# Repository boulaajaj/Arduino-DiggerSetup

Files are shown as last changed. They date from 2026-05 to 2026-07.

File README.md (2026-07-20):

# 🚜 Excavator Track Controller

**Tank-style dual-track controller for a ride-on excavator, built on the
Arduino UNO R4 WiFi.** Two FOC brushless motors drive rubber tracks. Two people
can drive it — an RC transmitter operator and a seated rider on a joystick — and
a 3-position switch decides who has authority. Live motor telemetry streams to a
Wi-Fi dashboard you open on your phone.

> The controller's job is deliberately small and predictable: **read the inputs,
> shape them, mix them into left/right track commands, cap them by gear, and send
> a servo-PWM throttle to each ESC.** The ESC's internal FOC owns motor smoothness,
> so there is no closed-loop control or lag on the Arduino side.

---

## ✨ What It Can Do

- **Tank / curvature mixing** — one stick (or wheel + trigger) blends into smooth
  left/right track control; counter-rotating **pivot turn** on the spot at a standstill.
- **Two drivers, one machine** — RC transmitter *and* a rider joystick, with a
  3-position override switch (RC-only / RC-priority / 50-50 blend).
- **Gear caps** — Eco / Normal / Boost wheel-speed limits selectable from the remote.
- **Exponential response curves** — separate throttle and steering expo for fine,
  controllable low-speed handling.
- **Instant failsafe** — loss of the RC signal holds both tracks at neutral.
- **Live Wi-Fi telemetry dashboard** — per-track voltage, current, RPM, power,
  ESC/motor temperatures and battery state, served straight off the board
  (monitoring only — there is no control over Wi-Fi, by design).

---

## 🧰 Uses (Hardware)

| Part | Model | Notes |
| --- | --- | --- |
| **Controller** | **Arduino UNO R4 WiFi** | Renesas RA4M1 (48 MHz, 14-bit ADC, 5 V-tolerant) + onboard ESP32-S3 for Wi-Fi. *(This project ran on a Nano R4 earlier — it does not anymore.)* |
| **ESC ×2** | XC **GL10 80A FOC** | Standard 50 Hz servo-PWM input, internal field-oriented control, IP67. |
| **Motor ×2** | XC **GL540L** | Sensored brushless, paired to the GL10 — one per track. |
| **Battery ×2** | OVONIC 3S LiPo 15000 mAh 130C | 11.1 V, EC5 — one pack per side. |
| **RC system** | Radiolink RC6GS V3 + R7FG | 6-channel gun-style radio over S.BUS (trigger = throttle, wheel = steering). |
| **Joystick** | Genie 101174GT dual-axis | 5 V, 0–5 V analog hall-effect, wired straight to the ADC. |

The Arduino reads everything, does the tank mixing itself, and outputs a servo
PWM throttle (1000–2000 µs) per track on D9/D10. Full wiring lives in
[`docs/WIRING-GUIDE-V8.md`](docs/WIRING-GUIDE-V8.md).

---

## 🎮 Controls

### RC transmitter (supervisor)

- **Trigger = throttle, wheel = steering** — the Arduino mixes these into the two
  tracks.
- **3-position switch (CH5)** selects the override mode (below).
- **Gear switch (CH4)** selects Eco / Normal / Boost.
- Moving the controls takes priority over the joystick in RC-priority mode, so the
  supervisor can always step in.

### Joystick (rider)

The rider drives with a single dual-axis stick:

| Stick | Result |
| --- | --- |
| **Forward** | Both tracks forward — drive straight ahead |
| **Back** | Both tracks reverse |
| **Right** | Left track forward + right track back — turn right |
| **Left** | Right track forward + left track back — turn left |
| **Diagonal** | Blends forward/back with turning (curvature drive) |
| **Right/left at a standstill** | **Pivot turn** — tracks counter-rotate on the spot (speed-capped, with extra authority in Eco) |

A deadband around center keeps the machine still when the stick is released, and
an expo curve makes small movements gentle for precise maneuvering. The
joystick throttle also carries a configured gain so it doesn't feel weaker
than the RC throttle — full deflection still tops out at the active gear cap.

### Override modes (3-position switch)

| Mode | Switch | Who drives |
| --- | --- | --- |
| **RC only** | Down | Supervisor has full control; joystick ignored |
| **RC priority** | Middle | Rider drives on the joystick; supervisor takes over instantly by moving the controls, hands back when centered |
| **50/50 blend** | Up | Both inputs averaged together — shared control |

### Gear caps (gear switch)

The gear sets the **average (straight-line) speed cap** — not a per-wheel limit.
In a turn, Eco and Normal let the *outer* track climb into the headroom up to the
ESC rail, so the machine **holds its speed through corners** instead of bogging
down. Boost is already at the rail, so it has no extra turn headroom.

| Gear | Straight-line speed | Use |
| --- | --- | --- |
| **Eco** | Slowest | Training / tight spaces (largest turn headroom; reverse & pivot get extra authority) |
| **Normal** | Medium | Everyday driving |
| **Boost** | Fastest | Full authority (at the rail — no turn headroom) |

Reverse is additionally capped below forward speed per gear, and pivot rotation
has its own speed cap. The exact percentages are tunables — the current values
live in `sketches/dual_track_control/src/config/`, and the operator-facing
table is in [OPERATOR-GUIDE.md](OPERATOR-GUIDE.md).

---

## ⚡ Power & Drivetrain

Each track is an independent power unit: a **GL540L** sensored brushless motor
driven by a **GL10 80A FOC** ESC, fed from its own **3S LiPo** pack.

- **Field-oriented control inside the ESC** — the GL10 turns the Arduino's PWM
  command into smooth phase currents with its own acceleration ramp and drag
  handling. The Arduino sends *what we want*; the ESC decides *how to spin the
  motor* to get there. No jerky starts, no Arduino-side PID.
- **80 A per ESC, IP67** — plenty of current headroom for a ~50 lb ride-on machine,
  and sealed against dust and water.
- **Dual 15000 mAh 130C packs** — high-discharge LiPos sized for sustained track
  loads; one per side keeps the two drivetrains electrically independent.
- **Open-loop by design** — the Arduino does **not** read RPM and correct the
  throttle. Stick position → PWM → ESC executes. Telemetry is read *only* for the
  dashboard and never feeds back into motor output (a permanent safety decision).

---

## 📡 Wi-Fi Telemetry Dashboard

The board hosts its own Wi-Fi access point (`Digger-Telemetry`) at
`192.168.4.1`. Connect a phone and the dashboard streams live data over
Server-Sent Events at ~5 Hz:

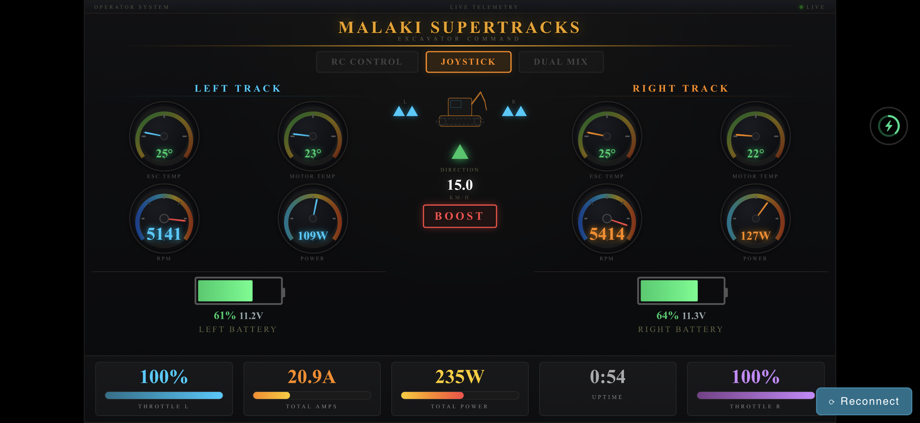
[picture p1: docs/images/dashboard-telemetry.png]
Live telemetry dashboard — per-track gauges, battery state, gear and throttle


- Per-track **voltage, current, power, RPM**, and **ESC + motor temperatures**
- **Battery state** for each pack
- Active **drive mode**, **gear**, and per-track **throttle/direction**

It's a **single-page app** that fits landscape on an iPhone or Android phone — no
app install, just connect to the AP and open the page (it can also be saved to
the home screen for a full-screen, browser-chrome-free view).

It's **monitoring only** — there is no path from Wi-Fi to the motors, ever. The
dashboard source is mirrored in [`dashboard/index.html`](dashboard/index.html).

---

## 🔧 Build & Upload

Board: **Arduino UNO R4 WiFi** · FQBN: `arduino:renesas_uno:unor4wifi`

```bash
# First checkout only: create your local Wi-Fi credentials (gitignored)
cp sketches/dual_track_control/arduino_secrets.h.example sketches/dual_track_control/arduino_secrets.h
# ...then edit it with the real SSID/password.

# Compile
arduino-cli compile --fqbn arduino:renesas_uno:unor4wifi sketches/dual_track_control

# Upload (serial port, e.g. COM7)
arduino-cli upload --fqbn arduino:renesas_uno:unor4wifi -p COM7 sketches/dual_track_control

# Monitor / live plot
python tools/monitor.py
python tools/live_plot.py
```

---

## 📚 Documentation

| Doc | What's inside |
| --- | --- |
| [`docs/ARCHITECTURE.md`](docs/ARCHITECTURE.md) | How the code is shaped and why — pipeline, safety model, key decisions |
| [`CONTRIBUTING.md`](CONTRIBUTING.md) | Real-time rules, workflow, and how to run every check locally |
| [`PROJECT-PLAN.md`](PROJECT-PLAN.md) | Full technical specification and pin map |
| [`OPERATOR-GUIDE.md`](OPERATOR-GUIDE.md) | Plain-language guide for the RC operator and the rider |
| [`docs/WIRING-GUIDE-V8.md`](docs/WIRING-GUIDE-V8.md) | Canonical hardware wiring reference |
| [`docs/GL10-PARAMETERS.md`](docs/GL10-PARAMETERS.md) | GL10 ESC parameters with code-context analysis |
| [`docs/XBUS-PROTOCOL.md`](docs/XBUS-PROTOCOL.md) | X.BUS telemetry protocol reference |
| [`docs/DECISION-LOG.md`](docs/DECISION-LOG.md) | Technical decision history |

The main firmware entry is
[`sketches/dual_track_control/dual_track_control.ino`](sketches/dual_track_control/dual_track_control.ino) —
a small composition root; the code lives in layers under its `src/`
(domain / application / ports / infrastructure — see
[`docs/ARCHITECTURE.md`](docs/ARCHITECTURE.md)).

---

> ⚠️ **Safety:** this drives a real ~50 lb ride-on machine with powerful motors.
> Keep it in line of sight, start in Eco gear, and make sure the supervisor can
> always reach the override switch.

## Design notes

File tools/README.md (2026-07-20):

# Dev tools

Human-run development tooling, one home (#123). CI/hook machinery lives in
`scripts/` — the split is deliberate: `scripts/` runs in pipelines,
`tools/` runs on a bench.

## Serial + telemetry (need the board on a COM port)

| Tool | Run | What it does |
| --- | --- | --- |
| `monitor.py` | `python tools/monitor.py` | Plain serial monitor |
| `live_plot.py` | `python tools/live_plot.py` | Real-time matplotlib plot of the debug CSV stream |
| `live_plot_telemetry.py` | `python tools/live_plot_telemetry.py` | Live plot of the X.BUS telemetry values |
| `deploy.py` | `python tools/deploy.py` | Compile + upload the production sketch via arduino-cli |

## Dashboard UI tests (no hardware — mock SSE + Playwright screenshots)

| Tool | Run | What it does |
| --- | --- | --- |
| `ui-test.mjs` | `npm run ui-test` | Renders the dashboard with mock frames, screenshots it |
| `ui-test-battery.mjs` | `npm run ui-test:battery` | Battery gauge states |
| `ui-test-battery-color.mjs` | `npm run ui-test:battery-color` | Battery color thresholds |
| `ui-test-safety.mjs` | `npm run ui-test:safety` | Low-battery banner (eco lock / hard cutoff) |
| `ui-test-thermal.mjs` | `npm run ui-test:thermal` | Thermal warning states |
| `drive-trace.mjs` | `npm run drive-trace` | Mirrors the curvatureDrive math to verify pivot/turn behavior without flashing |

## Hardware drawings (no hardware)

| Tool | Run | What it does |
| --- | --- | --- |
| `draw_perfboard.py` | `python tools/draw_perfboard.py` | Interface-board perfboard layout PNG |
| `draw_singlepad.py` | `python tools/draw_singlepad.py` | Single-pad drawing variant |

Dashboard UI testing policy: mock data + screenshots BEFORE flashing
(standing rule). The dashboard source of truth is `dashboard/index.html`;
`web_page.h` is generated.

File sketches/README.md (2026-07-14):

# Sketches

One production firmware, plus throwaway bench/bring-up tools kept for
reference. Only the production sketch follows the architecture rules
(`.claude/rules/architecture.md`); bench sketches are exempt by design.

## Production

| Sketch | What it is |
| --- | --- |
| `dual_track_control/` | **The shipped firmware** (V7.x lineage, renamed in #118): S.BUS + joystick input, curvature tank mix, gear caps, safety ladders, X.BUS telemetry, Wi-Fi dashboard. Everything under its `src/` tree. |

## Bench / bring-up tools

| Sketch | Purpose |
| --- | --- |
| `beeper_test/` | D8 piezo + SWD-horn bench test (#63; horn logic later moved into the firmware) |
| `hardware_diagnostic/` | RC pulse + ADC wiring diagnostic (pulseIn-based — bench only) |
| `pin_test/` | `attachInterrupt()` support test on D2/D3/D4/D7 |
| `sbus_test/` | LEGACY (Nano R4 era, S.BUS on D0) — superseded by `sbus_d12_test` |
| `sbus_d12_test/` | S.BUS-on-D12 (SCI0) bring-up for the UNO R4 WiFi |
| `telemetry_check/` | Read-only X.BUS telemetry bench tool (#36, 0x50 framing) |
| `telemetry_decode/` | Early X.BUS decode experiment (ADUM1201 @ 19200 + joystick direct drive) |
| `usb_test/` | USB CDC serial output sanity check |

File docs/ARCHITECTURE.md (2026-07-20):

# Architecture — how the code is shaped, and why

Written for a human engineer landing on the repo. The machine-checked
contracts live elsewhere (spec: [ARCHITECTURE-TARGET](architecture/ARCHITECTURE-TARGET.md),
inventory: [FILE-MAP](architecture/FILE-MAP.md), authority hierarchy:
[authority-matrix](wiki/authority-matrix.md)); this page is the narrative.

## The shape

The production sketch's `.ino` is a small composition root: it includes
the application layer, delegates `setup()`/`loop()`, and does nothing
else. Everything real lives under
`sketches/dual_track_control/src/` in one-way layers:

```text
.ino ─▶ application ─▶ domain      (pure logic: battery, thermal,
              │        operator_input, drive, safety — no hardware
              │        includes, time passed as a parameter)
              ├──────▶ ports       (hardware contracts, link-time seams)
              ├──────▶ telemetry   (read-only observers of one snapshot)
              ├──────▶ alerts      (beep policy + pattern players)
              └──────▶ config      (every tunable, per domain)
        infrastructure ─▶ ports    (the ONLY layer with hardware includes:
                                    Arduino core, S.BUS, X.BUS, Wi-Fi)
```

One sanctioned read-back: the telemetry and alert observers read a single
application-owned struct (the SystemSnapshot) — a data edge by design,
not a dependency inversion.

Domain logic is host-testable by construction: the test suites compile the
REAL firmware against a stub Arduino environment, and the pure-domain
suites compile without stubs at all — an accidental hardware include fails
the build loudly ([TESTING](TESTING.md)).

## The signal pipeline

One loop pass, in order (full walk with ordering invariants:
[application-loop](wiki/application-loop.md)):

1. **Inputs** — S.BUS frame (all channels in one frame, one freshness
   timeout) and the 14-bit joystick ADC on its own cadence.
2. **Protection ladders** — battery Eco-lock and cutoff, thermal stages —
   run BEFORE gear selection so a lock can force Eco.
3. **Shaping and mixing** — deadband, per-axis expo, then one
   `curvatureDrive` pass over the combined RC+joystick command: the gear
   cap bounds the AVERAGE track speed (the outer track keeps turn
   headroom), pivot mode blends in smoothly at standstill.
4. **Safety decision + output gate** — drive-allowed is decided from RC
   freshness, battery confirmation, the cutoff latch, and the thermal cut;
   the gate executes ACTIVE → ease-to-neutral → CUT (ESCs lose signal and
   failsafe), re-attaching on recovery.
5. **Watchdog refresh — the only refresh point, directly after the control
   path.** Any stall below misses it, the MCU resets, PWM stops, the
   machine stops. This is the runaway backstop.
6. **Observers** — X.BUS telemetry poll and the Wi-Fi dashboard, both
   strictly read-only with respect to control.

Current values for every threshold and cap live in
`sketches/dual_track_control/src/config/` — no document carries a live
copy, by rule.

## The safety model

- **Battery ladder** (three escalating stages: Eco lock, audible alarm,
  motor cutoff that LATCHES until power-cycle) with a plausibility filter
  so garbage telemetry can neither trip nor release it. A boot gate holds
  drive until a valid reading confirms the pack after a reset wipes the
  latch — and deliberately fails OPEN if telemetry never reports, so a
  dead sensor bus cannot permanently disable driving.
- **Thermal stages** with hysteresis — a stage releases at a lower
  temperature than it trips, so the machine never oscillates at a
  boundary; unlike the battery cutoff, the thermal cut auto-recovers when
  the motor cools and the gate re-attaches the ESCs (RC-loss recovery
  behaves the same way).
- **Output gate state machine** — neutral is commanded and held before PWM
  is cut, so the ESC decelerates smoothly instead of freewheeling.
- **Three permanent invariants**: control is open-loop (telemetry never
  feeds throttle — a bad sensor cannot command motion); there is no
  control path over Wi-Fi (the dashboard can only watch); and the
  hardware watchdog is refreshed exactly once per pass, directly after
  the control path — never anywhere else. All are locked by executable
  invariant tests ([SAFETY](SAFETY.md)).

Every invariant maps to a host test that drives the real `loop()` under
injected faults and re-checks the property after every pass.

## Key decisions, with receipts

Dated rationale lives in [DECISION-LOG](DECISION-LOG.md); the big ones:

- **FOC in the ESC, not PID on the Arduino** — the GL10's internal
  field-oriented control owns motor smoothness, so the Arduino-side
  dual-loop PID plan was retired and the firmware's job shrank to
  shaping, mixing, capping, and gating (2026-04-25).
- **Telemetry via X.BUS Read Register, never bulk throttle** — the
  read-only service function preserves full PWM control authority; the
  bulk function would seize it.
- **Hardware UARTs only for telemetry** — bit-banged serial input is
  banned on the control board.
- **Bounded Wi-Fi serving** — capped modem writes, ETag/304 caching, and
  incremental page transfer keep the dashboard from ever stalling the
  control loop (the watchdog would catch it; the design avoids it).

## What runs where

- **RA4M1 (the Arduino's Cortex-M4)** — everything in this repo's `src/`:
  the pipeline, ladders, gate, watchdog, telemetry poll, HTTP/SSE serving.
- **ESP32-S3 (the UNO R4 WiFi's radio coprocessor)** — the Wi-Fi modem,
  driven through the core's AT-command bridge; no application code runs
  there today.
- **GL10 ESCs** — field-oriented commutation, acceleration and drag-brake
  shaping, and their own low-voltage/thermal protections, all internal;
  the Arduino speaks plain 50 Hz servo PWM to them.

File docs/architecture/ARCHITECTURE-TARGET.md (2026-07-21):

# Target Architecture — Dual Track Control

**Status:** adopted 2026-07-05 (epic #116, issue #128, ADR-0001)
**Applies to:** the production firmware in `sketches/dual_track_control/`
(carried its former bring-up name until the #118 rename)

This document is the contract for the Phase D refactor (#117, #130, #132) and
the rulebook the CI architecture fitness functions (#129) enforce. Bench
sketches (`sketches/*_test/`, `hardware_diagnostic`, …) are exempt — they are
throwaway bring-up tools by design.

---

## 1. Why this architecture

The firmware has two jobs: drive a real machine safely, and demonstrate how a
growing, safety-aware, multi-domain embedded system is engineered. The current
single 1606-line `.ino` works, but its `[MODULE]` comment sections are
navigation, not boundaries — nothing stops a Wi-Fi function from reading a
safety latch directly, and none of the control math can run off-target.

The target: **domain logic that could run on a laptop, hardware access behind
explicit ports, one owner per piece of state, and a composition root that reads
like the signal-flow diagram.**

## 2. Target tree

```text
sketches/dual_track_control/
├── dual_track_control.ino        ← composition root ONLY (~20-30 lines)
└── src/
    ├── application/              ← orchestration: wires domains + ports, owns the cycle
    │   ├── FirmwareApp.h/.cpp    ← setup()/tick() entry, owns module instances
    │   ├── ControlCycle.h/.cpp   ← one pass: read → decide → gate → write → observe
    │   └── SystemSnapshot.h      ← immutable per-cycle state for observers (#132)
    │
    ├── domain/                   ← pure logic. NO Arduino/hardware includes. Host-compilable.
    │   ├── drive/
    │   │   ├── DriveTypes.h              (DriveIntent, TrackCommand, WheelSpeeds)
    │   │   ├── CurvatureDrive.h/.cpp     (curvature mix + desaturation)
    │   │   ├── PivotPolicy.h/.cpp        (pivot cap, blend band, throttle taper)
    │   │   ├── GearPolicy.h/.cpp         (gear scale, per-gear caps, reverse cap)
    │   │   └── CommandMixer.h/.cpp       (max/oppose RC+joystick combine)
    │   ├── operator_input/
    │   │   ├── InputTypes.h              (OperatorInput, normalized axes)
    │   │   ├── DeadbandPolicy.h/.cpp
    │   │   ├── ExpoCurve.h/.cpp
    │   │   └── InputNormalization.h/.cpp (raw→[-1,1], gains, polarity)
    │   ├── battery/
    │   │   ├── BatteryTypes.h            (BatteryReading, BatteryStatus)
    │   │   ├── VoltagePlausibility.h/.cpp(validity + worst-of-two — ONE implementation)
    │   │   └── BatteryLadder.h/.cpp      (Eco lock, low-V alarm level, cutoff, boot gate)
    │   ├── thermal/
    │   │   ├── ThermalTypes.h            (ThermalReading, ThermalStage)
    │   │   ├── ThermalHysteresis.h/.cpp  (one stage: on/off thresholds + trip debounce)
    │   │   └── ThermalDerating.h/.cpp    (warn / eco / cut staging off hottest sensor)
    │   └── safety/
    │       ├── SafetyTypes.h             (SafetyInputs, SafetyDecision, FailsafeReason)
    │       ├── SafetySupervisor.h/.cpp   (battery + thermal + RC freshness → decision)
    │       └── OutputGate.h/.cpp         (ACTIVE/HOLD/CUT state machine, ease-out ramp)
    │
    ├── ports/                    ← tiny headers; hardware contracts consumed by
    │                               application/ — they speak domain types, but
    │                               domain/ itself never includes them
    │   ├── ClockPort.h           (now µs/ms)
    │   ├── RcInputPort.h         (channels + freshness)
    │   ├── JoystickPort.h        (raw ADC pair)
    │   ├── EscOutputPort.h       (µs per track; attach/detach)
    │   ├── TelemetrySource.h     (EscTelem per ESC)
    │   ├── TelemetrySink.h       (SystemSnapshot out)
    │   └── AlertOutputPort.h     (piezo on/off)
    │
    ├── infrastructure/           ← the ONLY layer that includes hardware libraries
    │   ├── arduino/              (ArduinoClock, PwmEscAdapter, PiezoAdapter, AdcJoystickAdapter, WatchdogAdapter)
    │   ├── radiolink/            (SbusReceiverAdapter — sbus lib + inverted-UART detail)
    │   ├── xc/                   (XbusTelemetryAdapter — 0x10 poller, framing, checksum)
    │   └── network/              (WifiService, DashboardServer, SseStream — non-blocking rules live here)
    │
    ├── telemetry/                ← observers: encode SystemSnapshot for sinks
    │   ├── TelemetryScaling.h    (×10 integer scaling — ONE implementation)
    │   ├── JsonEncoder.h/.cpp    (SSE //data payload)
    │   └── CsvEncoder.h/.cpp     (USB debug stream)
    │
    ├── alerts/                   ← beep vocabulary + priority (domain-ish, no hardware)
    │   ├── AlertTypes.h          (AlertView, patterns)
    │   ├── AlertPolicy.h/.cpp    (priority: thermal-cut > low-V > thermal-warn > inactivity)
    │   └── PatternPlayer.h/.cpp  (non-blocking on/off sequencing)
    │
    ├── config/                   ← ALL tunables, grouped by domain (replaces [CONFIG])
    │   ├── DriveConfig.h  SafetyConfig.h  BatteryConfig.h  ThermalConfig.h
    │   ├── InputConfig.h  TelemetryConfig.h  WifiConfig.h  AlertConfig.h
    │   ├── Pins.h                (every pin assignment in one file)
    │   └── BuildInfo.h           (FIRMWARE_VERSION — single source of truth, #124)
    │
    └── generated/                ← machine-written only; never hand-edited (#120)
        └── web_page.h
```

`tests/` (host-side, #47/#131) lives at repo root, mirroring `domain/`
subfolders plus `characterization/` and `invariants/`.

## 3. Layers and dependency rules

| Layer | May depend on | Must NOT depend on |
| --- | --- | --- |
| `domain/` | other `domain/` headers, `config/` | `Arduino.h`, `WiFiS3.h`, `Servo.h`, SBUS lib, X.BUS/GL10 code, `ports/`, `infrastructure/`, `application/` |
| `ports/` | plain types from `domain/` | any hardware library |
| `application/` (incl. its observer submodules `telemetry/`, `alerts/`) | `domain/`, `ports/`, `config/` | `infrastructure/` internals (talks through ports) |
| `infrastructure/` | `ports/`, hardware libraries, `config/` | `domain/` internals (plain types via ports only), `application/` |
| `telemetry/`, `alerts/` (observer ring of the application layer) | `application/SystemSnapshot.h` ONLY from application/, plus `domain/` types, `config/` | hardware libraries, any other `application/` header, domain *internals* (mutable state) |
| `generated/` | — | hand edits |
| `.ino` | `application/` only | everything else |

`telemetry/` and `alerts/` are part of the **application layer** (its observer
ring), not a separate layer — so application orchestration calling them is
within-layer, not a cross-layer cycle. At file level the graph stays acyclic:
`SystemSnapshot.h` includes nothing from `telemetry/` or `alerts/`, and those
folders may include no `application/` header except `SystemSnapshot.h`. The
fitness checks (#129) enforce exactly that file-level rule.

Three non-negotiables, enforced by #129:

1. **`domain/` compiles on the host** with no Arduino includes.
2. **No namespace-scope mutable state in `domain/`.** Modules own state via
   structs passed explicitly (or objects held by `application/`).
3. **Time is a parameter.** Domain code never calls `millis()`/`micros()`;
   `ControlCycle` reads `ClockPort` once per pass and passes `now` down.

## 4. Control flow (one cycle)

```text
   SbusReceiverAdapter   AdcJoystickAdapter        XbusTelemetryAdapter
        │ RcInputPort         │ JoystickPort             │ TelemetrySource
        ▼                     ▼                          ▼
   ┌────────────────────────────────┐            ┌───────────────────┐
   │ operator_input:                │            │ battery:          │
   │ normalize → deadband → expo →  │            │ plausibility →    │
   │ gains → OperatorInput          │            │ ladder            │
   └───────────────┬────────────────┘            │ thermal:          │
                   ▼                             │ hysteresis stages │
   ┌────────────────────────────────┐            └─────────┬─────────┘
   │ drive: CommandMixer →          │                      │
   │ GearPolicy → PivotPolicy →     │                      ▼
   │ CurvatureDrive → TrackCommand  │            ┌───────────────────┐
   └───────────────┬────────────────┘            │ safety:           │
                   │       proposed command      │ SafetySupervisor  │
                   └──────────────┬──────────────┤ → SafetyDecision  │
                                  ▼              └───────────────────┘
                        ┌───────────────────┐
                        │ safety:OutputGate │  ACTIVE / HOLD(ease) / CUT
                        └─────────┬─────────┘
                                  ▼ approved µs
                        ┌───────────────────┐
                        │ EscOutputPort →   │
                        │ PwmEscAdapter     │
                        └───────────────────┘

   ControlCycle then builds ONE immutable SystemSnapshot and hands it read-only to:
      telemetry/JsonEncoder → SSE/dashboard      (monitoring only — permanent rule)
      telemetry/CsvEncoder  → USB debug
      alerts/AlertPolicy    → PatternPlayer → AlertOutputPort (piezo)
```

The permanent safety rules are unchanged by this refactor: **open-loop control**
(telemetry never feeds throttle), **no control input over Wi-Fi, ever**, and the
watchdog refresh stays exactly once per cycle, after the control path.

## 5. State ownership

**One domain owns its state; no other domain writes it.** The concrete sins
this outlaws (all present in `dual_track_control.ino` today):

- `[SAFETY]` writing `[ALERT]`'s `lowVoltLatched` → instead `SafetyDecision`
  carries `alarmRequested`; `AlertPolicy` reads it and owns its own latch.
- `curvatureDrive()` silently reading the `currentGear` global → gear is a
  field of the input it receives.
- Wi-Fi/debug scraping ~30 globals → observers read `SystemSnapshot` only.

`SystemSnapshot` (#132) is built once per cycle by `application/` and passed
`const&` to every observer. Observers cannot write, and cannot see two
different cycles in one frame.

## 6. File and naming policy

- **Soft limit 150 lines** per human-written source file (one screenful);
  **hard CI fail at 250**; exemptions in `.architecture-allowlist` with a
  written reason (generated files, lookup tables).
- One file = one concept. Splitting `Foo.cpp` into `FooPart2.cpp` to duck the
  limit is a review reject — split by *responsibility* or don't split.
- Sketch/dir names `lowercase_snake_case` (structure-check CI). C++ types
  `PascalCase`, functions `camelCase`, constants `UPPER_SNAKE_CASE`, pins
  `PIN_*` (unchanged from today's rules).
- **Banned file names:** `Utils`, `Helpers`, `Helper`, `Manager`, `Common`,
  `Misc`, `Stuff`, `Data`. A `helpers/` *folder* inside a domain is allowed
  only when every file in it names one precise responsibility
  (e.g. `drive/helpers/Smoothstep.h`) — never a grab-bag file.
- Domain language over mechanism language: `OutputGate`, not `PwmManager`;
  `FailsafeReason`, not `ErrorCode`.

## 7. Ports & adapters strategy

Ports are **small headers** owned by the consuming side; adapters implement
them in `infrastructure/`. Preference order:

1. **Link-time substitution** (default): the firmware build links the Arduino
   adapter, the host test build links a fake. Zero runtime cost, no vtables.
2. **Virtual interfaces** only where implementations genuinely swap at runtime
   (none identified today).

No Arduino type may appear in a port signature — ports speak `domain/` types
and primitives.

## 8. Ubiquitous language

| Term | Meaning |
| --- | --- |
| `OperatorInput` | Normalized post-shaping axis pair from one input source |
| `DriveIntent` | Mixed, gear-capped command before safety review |
| `TrackCommand` | Per-track normalized output (−1..+1) |
| `ServoOutput` | Per-track µs (1000–2000) |
| `SafetyDecision` | Supervisor verdict: allow / ease-to-stop / cut + `FailsafeReason` |
| `FailsafeReason` | Why drive is denied: RC_STALE, BATTERY_CUTOFF, THERMAL_CUT, BOOT_GATE |
| `BatteryLadder` | Staged response: Eco-lock 10.8 V → alarm 10.5 V → cutoff 10.0 V |
| `ThermalStage` | NORMAL / WARN (80°) / ECO (90°) / CUT (95°), hysteresis releases |
| `OutputGate` | ACTIVE / HOLD (ease to neutral) / CUT (no pulses) state machine |
| `SystemSnapshot` | Immutable per-cycle state for observers |
| `Gear` | Eco / Normal / Boost average-speed cap |

## 9. Migration plan (Phase D, #117)

Smallest, purest logic first — the pattern is proven before the propulsion
path moves:

1. `VoltagePlausibility`
2. `BatteryLadder`
3. `ThermalHysteresis` / `ThermalDerating`
4. `TelemetryScaling` + encoders
5. `operator_input/`
6. `CurvatureDrive`
7. `PivotPolicy` / `GearPolicy`
8. `SafetySupervisor`
9. `OutputGate`
10. `infrastructure/` adapters
11. `FirmwareApp` + composition-root `.ino`

**Rules for every migration PR** (operating constraints locked 2026-07-05):

- Behavior-preserving only; characterization tests (#47) green before/after.
- `arduino-cli compile --fqbn arduino:renesas_uno:unor4wifi` locally **before
  every push** — structure problems surface at step 1, not step 10.
- **No hardware available:** no flashing, no bench tests. Compile plus host
  tests plus review are the verification. Each PR appends any physical checks it would
  have run to `docs/architecture/BENCH-VERIFICATION-DEFERRED.md`; one bench
  pass executes that whole checklist when the machine returns.
- One extraction step per PR, own issue, draft PR from the first commit
  (board rules unchanged).

## 10. Enforcement

Rules in this document are enforced by the CI architecture fitness functions
(#129, shipped): forbidden includes, layer direction, file-size policy
(allowlist: `.architecture-allowlist`, reason required per entry), banned
names, no mutable domain globals, generated-file drift (activates with #120),
version SSOT (activates with #124). Implementation:
`scripts/check_architecture.py` + `scripts/architecture_rules.py`, run by the
`architecture-fitness` workflow after a self-test
(`scripts/check_architecture_selftest.py`) proves every failure mode fires.
The check is **advisory** (not in branch protection) until the operator
flips it to required (#196 — the Phase D extraction itself landed, #189). Section 3's table is canonical —
a rule change here must change the script in the same PR.

**Migration window (#150):** the composition-root rule (`.ino` →
`application/` only) activates once `src/application/FirmwareApp.h` exists —
the step-11 marker. During steps 1–10 the production `.ino` is the interim
application shell and may include extracted layers directly (the checker
emits a NOTE instead); extracted `src/` files are fully checked from step 1.

## 11. Testing strategy (summary — details in #47/#131)

| Level | What | Where |
| --- | --- | --- |
| 1 Pure domain | curvature, expo, deadband, gear/reverse caps, plausibility | `tests/<domain>/` |
| 2 State transitions | ladder debounce/latch, thermal hysteresis, output gate, explicit `now` | `tests/<domain>/` |
| 3 Characterization | current firmware behavior captured BEFORE refactor | `tests/characterization/` |
| 4 Invariants + faults | outputs bounded, stale-RC ⇒ neutral, cutoff dominates, monotone derating | `tests/invariants/` (#131) |
| 5 Adapters | S.BUS decode, X.BUS framing/checksum, JSON/CSV encoding | `tests/` |
| 6 Bench (deferred) | physical behavior per BENCH-VERIFICATION-DEFERRED.md | hardware, when available |

Level 4 landed with #131; the invariant registry (verbatim list, constants,
test links) is `docs/SAFETY.md`.

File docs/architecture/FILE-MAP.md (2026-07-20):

# Repository File Map

The annotated inventory of load-bearing files and directories — what each one
is and which issue shaped it. Moved verbatim from root `CLAUDE.md` (#197) so
the per-session context stays lean; this file is the detailed map's single
home. Layer rules live in `.claude/rules/architecture.md`; the canonical
architecture spec is [ARCHITECTURE-TARGET.md](ARCHITECTURE-TARGET.md).

```text
docs/ARCHITECTURE.md                     — Human-facing narrative: shape, pipeline, safety model, decisions (#126)
CONTRIBUTING.md                          — Human mirror of the agent rules: real-time law, workflow, local checks (#126)
PROJECT-PLAN.md                          — Full technical specification
OPERATOR-GUIDE.md                        — User guide for Jason (RC) and Malaki (joystick)
sketches/dual_track_control/dual_track_control.ino             — COMPOSITION ROOT ONLY (#189): includes src/application/FirmwareApp.h and delegates setup()/loop(); the firmware lives under src/
sketches/dual_track_control/types.h                 — Shared structs (JoystickState, ...; EscTelem re-exported from ports/TelemetrySource.h)
sketches/dual_track_control/src/domain/battery/     — Extracted domain (#117): BatteryTypes.h + VoltagePlausibility.h/.cpp + BatteryLadder.h/.cpp (pure logic, host-testable)
sketches/dual_track_control/src/domain/thermal/     — Extracted domain (#117): ThermalTypes.h + ThermalHysteresis.h/.cpp + ThermalDerating.h/.cpp (pure logic, host-testable)
sketches/dual_track_control/src/domain/operator_input/ — Extracted domain (#117): ExpoCurve.h/.cpp + DeadbandPolicy.h/.cpp (pure input shaping, host-testable)
sketches/dual_track_control/src/domain/drive/       — Extracted domain (#117): DriveTypes.h + CurvatureDrive.h/.cpp + GearPolicy.h/.cpp + CommandMixer.h/.cpp (curvature mix, gear policy, RC/joystick mixer)
sketches/dual_track_control/src/domain/safety/      — Extracted domain (#117): SafetyTypes.h + SafetySupervisor.h/.cpp + OutputGate.h/.cpp (drive allow/deny + FailsafeReason; ACTIVE/HOLD/CUT gate)
sketches/dual_track_control/src/application/        — The application layer (#189): FirmwareApp.h/.cpp (composition-root marker + the verbatim setup/loop control cycle) + FirmwareState + OperatorInput + MotorOutput + SafetyControl + AlertControl + Monitoring (module shims moved from the .ino) + SystemSnapshot.h (#132) + RangeMath.h (#187)
sketches/dual_track_control/src/telemetry/          — Extracted observer layer (#117): TelemetryScaling.h (×10 wire encode, header-only; register decode moved to infrastructure/xc/, #178) + JsonEncoder (dashboard JSON frame) + CsvEncoder (debug CSV line) — both read only the SystemSnapshot (#132)
sketches/dual_track_control/src/alerts/             — Alert policy + players (#183): AlertTypes.h + AlertPolicy (priority ladder, low-V latch, inactivity) + PatternPlayer (one-shot + repeating) — pure logic; the piezo stays behind ports/AlertOutputPort.h
sketches/dual_track_control/src/config/             — Tunables per domain (#185): BuildInfo.h (FIRMWARE_VERSION SSOT) + Pins.h + Input/Drive/Battery/Thermal/Alert/Telemetry/Wifi/SafetyConfig.h — values are law, included by src/application/FirmwareApp.h (adapter-owned tunables stay single-homed in infrastructure/)
sketches/dual_track_control/src/ports/              — Hardware contracts as link-time seams (#130): EscOutputPort.h + JoystickPort.h + AlertOutputPort.h + RcInputPort.h (RcFrame) + TelemetrySource.h (EscTelem) + DashboardServicePort.h + TelemetryFrameSource.h (reverse seam: app encodes, network ships bytes) + ClockPort.h + WatchdogPort.h + DebugConsolePort.h (#187 — the last hardware seams)
sketches/dual_track_control/src/infrastructure/     — The ONLY layer with hardware includes (#130): arduino/PwmEscAdapter.cpp (owns the Servos) + arduino/AdcJoystickAdapter.cpp (ADC settle + resolution) + arduino/PiezoAdapter.cpp + arduino/ArduinoClock.cpp + arduino/WatchdogAdapter.cpp + arduino/SerialConsoleAdapter.cpp (#187) + radiolink/SbusReceiverAdapter.cpp (owns sbusUart + the S.BUS parser) + xc/XbusTelemetryAdapter.h/.cpp (X.BUS 0x10 poller + register decode) + network/ (WifiService + DashboardServer + SseStream — the #69/#54/#77 serving machine + its tunables, #181)
sketches/dual_track_control/arduino_secrets.h.example — Wi-Fi credential template (#125); copy to arduino_secrets.h (gitignored)
sketches/dual_track_control/web_page.h              — GENERATED from dashboard/index.html (scripts/generate_web_page.py) — never hand-edit
sketches/telemetry_check/telemetry_check.ino     — X.BUS 0x50 telemetry bench tool: throttle hard-wired to 0, but 0x50 puts the ESC in BUS_MODE — bench only, never alongside PWM control (production uses 0x10)
sketches/sbus_d12_test/sbus_d12_test.ino — S.BUS-on-D12 bring-up test
dashboard/index.html                     — Wi-Fi dashboard SOURCE (single source of truth; web_page.h generated from it, #120)
docs/WIRING-GUIDE-V8.md                  — Canonical hardware wiring reference (UNO R4 WiFi)
docs/INTERFACE-BOARD-PERFBOARD.md        — Soldered interface board build
docs/GL10-Manual.pdf                     — XC-ESC official user manual (image-based, 3 pages)
docs/GL10-PARAMETERS.md                  — GL10 parameter reference + code-context analysis
docs/GL10-OPERATION.md                   — Startup, throttle calibration, factory reset, LED/beep reference
docs/XBUS-PROTOCOL.md                    — XC X.BUS protocol reference (used by live telemetry)
docs/CONTROL-RESEARCH.md                 — Tank mix, RC input, loop patterns research
docs/MISSION.md                          — Project design philosophy (smoothness above all)
docs/DECISION-LOG.md                     — Technical decision log
docs/TESTING.md                          — Host characterization + invariants suites + commit gate (#47, #131)
docs/SAFETY.md                           — Safety-invariant registry: propulsion-path invariants + test links (#131)
docs/AGENT-EXAMPLES.md                   — Good/bad task-execution pairs for AI agents (#53, real precedents)
docs/wiki/                               — AI-maintained knowledge graph (Obsidian-visualizable, links-only — no constants; #141)
tests/                                   — Host test harness: stub Arduino env + doctest suites (characterization/ + invariants/ cross-cutting; domain/ + telemetry/ + alerts/ mirror src/, #195)
.claude/skills/                          — Project skills (#127): safety-review, flash-and-log, new-module, field-tune, wiki-impact-review, prepare-pull-request (one procedure per folder)
.claude/agents/                          — Read-only reviewer subagents (#127): architecture, safety, tests, documentation
.githooks/pre-commit                     — Commit-time test gate (activate: git config core.hooksPath .githooks)
tools/                                   — Human-run dev tools with README index (#123): serial monitors/plotters, deploy, dashboard UI tests (Playwright + mock SSE), board drawings — scripts/ stays CI/hook machinery only
```

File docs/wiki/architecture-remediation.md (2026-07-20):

---
sources:
  - docs/architecture/ARCHITECTURE-TARGET.md
  - docs/DECISION-LOG.md
---

# Architecture remediation (epic #116)

Active program: reorganize the single-sketch firmware into a domain-oriented
structure — **without changing one observable behavior**
([governance](agent-governance.md)). Firmware flashed after any refactor must
drive exactly as before.

- **Target architecture** —
  [ARCHITECTURE-TARGET](../architecture/ARCHITECTURE-TARGET.md): layers
  (`application` / `domain` / `ports` / `infrastructure`), dependency rules,
  migration order; annotated file inventory in
  [FILE-MAP](../architecture/FILE-MAP.md) (#197)
- **Founding ADR** —
  [0001-domain-oriented-firmware-architecture](../architecture/adr/0001-domain-oriented-firmware-architecture.md)
- **Phases** — A Define → B Protect ([testing](testing.md) suites, done) →
  C Govern (CI fitness functions, done) → D Refactor (extract domains,
  **complete** — the sketch is a composition root and the check_ino
  fitness rule is active) → E Polish (next)
- **Extracted domains so far** — the [battery ladder](battery-ladder.md)'s
  voltage-plausibility gate and its two staged state machines (Eco lock,
  cutoff + boot gate) live in `src/domain/battery/`; the
  [thermal derating](thermal-derating.md) hysteresis stage, hottest-sensor
  selection, and warn/eco/cut staging live in `src/domain/thermal/`; the
  [X.BUS telemetry](xbus-telemetry.md) register-decode and ×10 wire-encode
  scaling lives in `src/telemetry/` (observer layer); the operator-input
  expo curve and center-snap deadband live in `src/domain/operator_input/`;
  the curvature tank mix — the propulsion-path core — plus the gear policy
  and the RC/joystick command mixer live in `src/domain/drive/`; the drive
  allow/deny supervisor (SafetyDecision + FailsafeReason) and the
  ACTIVE/HOLD/CUT [output gate](output-gate.md) state machine live in
  `src/domain/safety/`. All pure logic — no Arduino includes, time passed
  as a parameter, hardware effects returned as actions for the sketch to
  execute; the sketch keeps thin delegates until the composition root lands
- **Ports + adapters** — `src/ports/` link-time seams (ESC output,
  joystick ADC, piezo alert, RC input, ESC telemetry, dashboard service,
  clock, watchdog, debug console)
  with their `src/infrastructure/` adapters (`arduino/` + `radiolink/` +
  `xc/` + `network/`) owning the Servo objects, the ADC settle sequence,
  the piezo pin, the S.BUS UART + parser, the
  [X.BUS telemetry](xbus-telemetry.md) poller, and the
  [Wi-Fi dashboard](wifi-dashboard.md) serving machine: infrastructure is
  the only layer that includes hardware libraries, vendor types (the bfs
  S.BUS frame) are translated to domain types (`RcFrame`) at the port
  boundary, the telemetry port owns the `EscTelem` type it delivers while
  the sketch keeps owning the array, and the network layer only ever
  handles encoded bytes (the reverse `TelemetryFrameSource` seam)
- **Config is a layer** — every tunable lives in `src/config/` per-domain
  headers (BuildInfo carries the version single source of truth, Pins
  carries the application pin map); the `[CONFIG]` section of the sketch
  is now their include point, and values are law
- **Alerts are a layer** — the beep vocabulary lives in `src/alerts/`:
  `AlertPolicy` (the priority ladder, the low-voltage latch with its own
  plausibility form, inactivity tracking) + `PatternPlayer` (one-shot and
  repeating sequencing), all time-as-a-parameter; the piezo stays behind
  the alert output port and the final horn/pattern/alarm OR stays with the
  sketch shim ([safety system](safety-system.md))
- **Observers read a snapshot** — `src/application/SystemSnapshot.h` is the
  immutable per-cycle observation; the dashboard JSON and debug CSV
  encoders (`src/telemetry/`) consume it `const&` and can no longer reach
  into module internals ([telemetry and
  dashboard](telemetry-and-dashboard.md))
- **Protection first** — the [characterization and invariant
  suites](testing.md) were built BEFORE any code moves, so every refactor
  step is verified against locked behavior
- **Physical checks we cannot run** (no hardware during the program) are
  queued in
  [BENCH-VERIFICATION-DEFERRED](../architecture/BENCH-VERIFICATION-DEFERRED.md)
- Decisions land in the [DECISION-LOG](../DECISION-LOG.md) as they are made

Work is tracked on the GitHub project board — one issue per PR, one PR open
at a time ([.claude/rules/workflow](../../.claude/rules/workflow.md)).

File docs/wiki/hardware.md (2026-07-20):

---
sources:
  - docs/WIRING-GUIDE-V8.md
  - docs/GL10-PARAMETERS.md
---

# Hardware

Arduino **UNO R4 WiFi** (RA4M1 + ESP32-S3 Wi-Fi coprocessor) drives two
XC GL10 FOC ESCs paired with GL540L sensored brushless motors, powered by two
3S LiPo packs. Inputs: Radiolink RC system over [S.BUS](sbus-input.md) and a
hall-effect dual-axis joystick on the ADC. Canonical component table and pin
assignments: [CLAUDE.md](../../CLAUDE.md).

- [WIRING-GUIDE-V8](../WIRING-GUIDE-V8.md) — canonical wiring reference
- [INTERFACE-BOARD-PERFBOARD](../INTERFACE-BOARD-PERFBOARD.md) — soldered
  interface board (X.BUS merge + S.BUS inverter); design history in
  [INTERFACE-BOARD](../INTERFACE-BOARD.md) and netlist in
  [INTERFACE-BOARD-NETLIST](../INTERFACE-BOARD-NETLIST.md)
- [GL10-PARAMETERS](../GL10-PARAMETERS.md) — every ESC parameter analyzed
  against what the firmware actually commands (read before ANY ESC change)
- [GL10-OPERATION](../GL10-OPERATION.md) — calibration, factory reset, LED
  and beep codes; quick card: [GL10-QUICK-REFERENCE](../GL10-QUICK-REFERENCE.md)

The GL10's internal FOC owns motor smoothing — the Arduino sends open-loop
servo PWM commands only (see [control pipeline](control-pipeline.md)). The
hardware history (older sensored ESCs, the board migration) is recorded in
[CLAUDE.md](../../CLAUDE.md) and the [DECISION-LOG](../DECISION-LOG.md).

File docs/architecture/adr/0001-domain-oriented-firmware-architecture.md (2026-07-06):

# ADR-0001: Domain-oriented firmware architecture with enforced boundaries

**Status:** Accepted · 2026-07-05 · epic #116, issue #128

## Context

The production firmware is a single 1606-line `.ino` organized by `[MODULE]`
comment sections. It works and is well-documented, but:

- Comment sections are not boundaries — any function can read or write any of
  ~40 file-scope globals (e.g. the `[SAFETY]` module writes the `[ALERT]`
  module's `lowVoltLatched`; `curvatureDrive()` reads the `currentGear` global
  behind its parameter list).
- None of the control math can compile off-target, so there are no host tests
  on a safety-relevant propulsion path (issue #47 is blocked on this).
- The repo's own rule ("split at ~500 lines") and review guidance ("flag
  global state mutation") cannot be followed inside one `.ino`.
- The repository doubles as a portfolio demonstrating enterprise engineering
  practice; the architecture itself is a deliverable.

A real incident motivates the boundary discipline: a blocking ~33 KB Wi-Fi
page send froze `loop()` while the ESCs held the last throttle (#69). The fix
(incremental serving + watchdog) worked, but nothing structural prevents the
next accidental coupling between serving and control.

## Decision

Adopt the layered, domain-oriented architecture specified in
[`ARCHITECTURE-TARGET.md`](../ARCHITECTURE-TARGET.md):

1. **Layers with one-way dependencies:** `.ino` → `application/` →
   `domain/` + `ports/`; `infrastructure/` implements ports; observers read an
   immutable `SystemSnapshot`.
2. **Pure domain:** no Arduino/hardware includes, no namespace-scope mutable
   state, time passed as a parameter — every domain rule host-testable.
3. **Ports & adapters** with link-time substitution preferred over virtual
   interfaces (zero runtime cost on the 48 MHz RA4M1).
4. **One owner per piece of state;** cross-domain communication through
   returned decision/status types, never sideways writes.
5. **File policy:** ≤150 lines soft / 250 hard, allowlisted exceptions;
   generic names (`Utils`, `Helpers`, `Manager`, …) banned.
6. **CI-enforced:** architecture fitness functions (#129) fail the build on
   forbidden includes, layer violations, oversized files, banned names,
   mutable domain globals, and generated-file drift.

Migration is behavior-preserving, smallest-pure-logic-first (#117), protected
by characterization tests (#47) and safety invariants (#131), with a local
`arduino-cli` compile before every push. While no hardware is available,
physical checks accumulate in `BENCH-VERIFICATION-DEFERRED.md` for one bench
pass later.

## Consequences

**Positive:** propulsion math testable on a laptop with deterministic time;
state ownership explicit; the #69 class of coupling becomes a CI failure, not
a field discovery; new domains (e.g. future attachments) get an obvious home;
the repo demonstrates architecture governance, not just architecture diagrams.

**Negative / accepted costs:** more files and folders than a hobby sketch
needs (deliberate — showcase is a stated goal); some indirection when tracing
a value from stick to ESC (mitigated by the control-flow diagram and naming);
migration effort spread over ~11 PRs; contributors must learn the dependency
rules (enforced by CI, documented in CONTRIBUTING.md, #126).

**Rejected alternatives:**

- *Flat `.h/.cpp` pairs per `[MODULE]`* (original #117): reproduces the same
  coupling with more files; no host-testability guarantee.
- *Virtual-interface hexagonal everywhere:* unnecessary runtime indirection;
  link-time seams give the same inversion for free.
- *Full RTOS / event-driven rewrite:* out of scope; the superloop is simple,
  proven, and appropriate at ~20 kHz.

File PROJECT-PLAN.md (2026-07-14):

# Excavator Track Controller — Project Plan

## What This Does

An **Arduino UNO R4 WiFi** sits between an RC receiver and two FOC ESCs,
implementing a **tank-style mixer** with a secondary joystick input for the
rider. The RC transmitter (Jason) can always override via a 3-position switch.

The controller's job is deliberately small: **read inputs, shape them, mix them,
cap them by gear, and output a servo-PWM throttle/reverse command to each ESC.**
The GL10 ESC's internal FOC owns motor smoothness and compensation, so there is
**no Arduino-side closed-loop control**.

The controller provides:

- **Curvature/tank mixing** — symmetric add + desaturate, smoothstep blend into pivot
- **Exponential response curve** — separate throttle/steering expo for fine low-speed control
- **Gear caps** — Eco / Normal / Boost average-speed limits on RC CH4 (outer track keeps turn headroom)
- **Override switch** — RC-only / RC-priority / 50-50 blend on RC CH5
- **Per-channel failsafe** — neutral hold when S.BUS is invalid
- **X.BUS telemetry (monitoring only)** — V / I / RPM / temps streamed to a Wi-Fi dashboard

---

## Control strategy (read this first)

**The Arduino sends the throttle/reverse command as servo PWM. The GL10's FOC
executes it.** Two chips, two jobs:

| Who | Job |
| --- | --- |
| **Arduino (RA4M1)** | Decides *what we want*: read RC + joystick → expo/deadband → curvatureDrive mix → gear cap → output servo PWM (1000–2000 µs) per track on D9/D10. |
| **GL10 ESC (internal FOC)** | Decides *how to spin the motor* to hit that command smoothly: phase currents, acceleration ramp, drag — all inside the ESC. |

- **Open-loop command.** The Arduino does **not** read RPM and correct the
  output. Stick position → PWM → ESC executes. The earlier dual-loop current+RPM
  PID / feedforward / inertia filter (from the previous sensored-ESC setup) is
  **gone** — superseded by the GL10's internal FOC.
- **Telemetry is monitoring-only.** X.BUS Read Register (0x10) is polled
  read-only for the dashboard; it is never fed back into the throttle, and there
  is no path from Wi-Fi to motor output.

---

## Hardware

| # | Component | Model | Key Specs |
| --- | --- | --- | --- |
| 1 | Controller | Arduino **UNO R4 WiFi** | Renesas RA4M1 (48 MHz, 14-bit ADC, 5 V tolerant) + ESP32-S3 (Wi-Fi) |
| 2 | Battery (x2) | OVONIC 3S LiPo 15000 mAh 130C | 11.1 V, EC5 |
| 3 | ESC (x2) | **XC GL10 80A FOC** | Standard 50 Hz servo PWM in, internal FOC, IP67 |
| 4 | Motor (x2) | **XC GL540L** | Sensored brushless, paired with GL10 |
| 5 | RC System | Radiolink RC6GS V3 + R7FG | 6CH, S.BUS; gun-style (trigger = throttle, wheel = steering) — the **Arduino** does the tank mixing |
| 6 | Joystick | Genie 101174GT dual-axis | 5 V, 0-5 V analog, hall-effect (direct to ADC) |

> **History:** the project previously ran XC sensored ESCs/motors with an
> Arduino-side dual-loop PID. Swapped to GL10 + GL540L on 2026-04-25, then
> migrated from Nano R4 to UNO R4 WiFi for onboard Wi-Fi telemetry.

---

## Pin Map (UNO R4 WiFi)

```text
A0  ← Joystick Y (throttle)            [14-bit ADC, 0-5V direct (5V tolerant)]
A1  ← Joystick X (steering)            [14-bit ADC, 0-5V direct (5V tolerant)]
D11    (sbusUart TX on SCI0 — unused; S.BUS is RX-only)
D12 ← S.BUS RX (sbusUart on SCI0 via NPN inverter)   [100k 8E2]
D8     (reserved — future battery-aware beeper)
D9  → Left Track ESC                   [Servo PWM, 50 Hz, 1000-2000 us]
D10 → Right Track ESC                  [Servo PWM]
D0/D1 → Serial1 (X.BUS half-duplex telemetry bus to both ESCs, 115200 8N1)
USB-C → USB CDC Serial (debug + firmware upload)
VIN ← BEC / battery (7-24V)
GND → All components (common ground)
```

Full wiring spec: `docs/WIRING-GUIDE-V8.md`. Interface board: `docs/INTERFACE-BOARD-PERFBOARD.md`.

---

## Signal Pipeline

```text
RC (S.BUS) ──► curvatureDrive ──┐
                                ├─► override mixer ─► gear cap ─► servo PWM (D9/D10) ─► GL10 ESCs
Joystick (ADC) ──► curvatureDrive ─┘

X.BUS telemetry (Serial1, read-only) ──► EMA ──► Wi-Fi dashboard (monitoring only)
```

### Override Switch (RC CH5)

| Position | Mode | Who Controls |
| --- | --- | --- |
| LOW | RC only | Jason has full authority, joystick disabled |
| MID | RC priority | RC overrides when non-neutral |
| HIGH | 50/50 blend | RC + joystick averaged |

### Gear Caps (RC CH4)

The gear caps the **average** track speed (not each wheel). In a turn the outer
track uses the headroom up to the ±1.0 ESC rail, so Eco/Normal hold their speed
through corners; Boost is already at the rail.

| Position | Avg-speed cap | Use |
| --- | --- | --- |
| Eco | 65% | training / tight spaces (~35% turn headroom; reverse & pivot get extra authority) |
| Normal | 80% | normal driving — the everyday gear (~20% turn headroom) |
| Boost | 100% | full authority (at the rail) |

Reverse is capped per gear (55% Eco/Normal, 65% Boost — true percentages since
the 2026-07-03 ESC recalibration); pivot at 60% (72.5% in Eco). The
pivot↔drive hand-off smoothstep-blends across |throttle| 5–55% so there's no
snap at low speed, and the pivot branch's throttle is tapered by steering
(#114) so feeding throttle mid-turn arcs the machine out of the pivot instead
of surging it forward. The joystick throttle carries a ×1.40 gain (clamped to
the per-gear caps).

> Failsafe: when S.BUS is invalid, the controller holds neutral and gear stays at Eco.

---

## Telemetry (live, monitoring-only)

- **X.BUS Read Register (func 0x10)** on Serial1 (D0/D1) — NOT Throttle (0x50),
  which would put the ESC into BUS_MODE and fight our PWM.
- **Registers:** 0x0C VbatBus (×0.1 V), 0x0D IbusBus (×0.1 A), 0x02 motSpeed
  (electrical Hz), 0x20 mos-Tem, 0x22 mot-Tem (raw − 40 °C).
- **Cadence:** non-blocking, alternating ESCs (~30-40 Hz/ESC underlying), EMA on
  V/I/temps, instantaneous RPM, 5 s per-ESC freshness watchdog.
- **Wi-Fi dashboard:** UNO R4 WiFi AP `Digger-Telemetry` at `192.168.4.1`,
  Server-Sent Events at ~5 Hz (`SSE_INTERVAL_MS = 200`), page served from flash.
  **Monitoring only — no control input over Wi-Fi, ever.**

---

## Build & Upload

```bash
# Compile
arduino-cli compile --fqbn arduino:renesas_uno:unor4wifi sketches/dual_track_control

# Upload (COM7)
arduino-cli upload --fqbn arduino:renesas_uno:unor4wifi -p COM7 sketches/dual_track_control

# Monitor / plot
python monitor.py
python live_plot.py
```

---

## Status

> Current firmware version: `FIRMWARE_VERSION` in
> `sketches/dual_track_control/dual_track_control.ino` `[CONFIG]` (single source of truth, #124).
> Live feature status: CLAUDE.md "Implementation Status". The list below is
> a historical snapshot.

### Done

- [x] GL10 + GL540L hardware swap (2026-04-25)
- [x] S.BUS input on `sbusUart` (SCI0 / D12) via NPN inverter
- [x] curvatureDrive tank mixing + per-axis expo + pivot authority
- [x] Removed Arduino-side inertia / PID (GL10 FOC owns smoothing)
- [x] Gear caps (Eco 65% / Normal 80% / Boost 100%) capping average speed, outer-track turn headroom
- [x] Eco reverse/pivot boost; joystick throttle gain (retuned since — current value in `[CONFIG]`)
- [x] Smooth pivot↔drive blend (wide 5–55% band) — no snap at low throttle (#72)
- [x] Migrated Nano R4 → UNO R4 WiFi
- [x] Soldered interface board (X.BUS merge + S.BUS inverter)
- [x] X.BUS 0x10 telemetry live — both ESCs (V / I / RPM / temps)
- [x] Wi-Fi telemetry dashboard (SSE ~5 Hz, monitoring-only)
- [x] Battery + inactivity alarms on D8 (V7.12)
- [x] Loop watchdog — runaway/stall failsafe drops ESCs to neutral (V7.13)
- [x] Field test at reduced power

### Pending

- [ ] Wi-Fi serving latency mitigation (issue #54 — hardware-gated)
- [ ] Track-speed asymmetry investigation — per-ESC throttle calibration
- [ ] Low-battery motor cutoff (issue #65 — alarm is sound-only today)
- [ ] Current-sensor wiring/calibration on A2/A3 (issue #5)

---

## File Map

```text
sketches/dual_track_control/
  dual_track_control.ino       — Main controller sketch (version: FIRMWARE_VERSION in [CONFIG])
  types.h           — Shared structs (JoystickState, EscTelem, ...)
  web_page.h        — Embedded Wi-Fi dashboard (PROGMEM), served at "/"
sketches/telemetry_check/ — Read-only X.BUS telemetry bench tool (0x50 framing)
sketches/sbus_d12_test/ — S.BUS-on-D12 bring-up test
docs/WIRING-GUIDE-V8.md        — Canonical hardware wiring reference (UNO R4 WiFi)
docs/INTERFACE-BOARD-PERFBOARD.md — Soldered interface board build
docs/XBUS-PROTOCOL.md          — XC X.BUS protocol reference (used by telemetry)
docs/GL10-PARAMETERS.md        — GL10 parameter reference + code-context analysis
docs/DECISION-LOG.md           — Technical decision log
dashboard/index.html           — Wi-Fi dashboard source (mirror of web_page.h)
live_plot.py / monitor.py      — Serial monitors
PROJECT-PLAN.md                — This file
```

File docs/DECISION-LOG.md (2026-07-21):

# Decision Log

Technical decisions, test results, and confirmed hardware facts.
Updated by session hooks — only technical content, no personal info.

---

## 2026-07-21 — dashboard version badge injected from the SSOT (#222)

- dashboard/index.html carries {{FIRMWARE_VERSION}}; generate_web_page.py
  substitutes the BuildInfo.h value (regex-anchored, fail-close on a
  missing declaration or wrong placeholder count). The badge had drifted
  twice (V7.33 shown vs V7.35 SSOT) — impossible now: a version bump
  without regenerating web_page.h fails the dashboard-drift CI check, so
  bumps and regeneration travel in the same commit by construction.

## 2026-07-20 — epic #116 closed; covenant made permanent (#203)

- Epic #116 closed with all child issues done (operator go-ahead). The
  behavior-preservation covenant survives the epic as PERMANENT policy —
  one home: .claude/rules/behavior-preservation.md. Epic-conditioned
  wording retired from CLAUDE.md, workflow rule, copilot-instructions
  (covenant section retitled permanent), .coderabbit.yaml ([epic #116]
  markers → [covenant]; "mid-refactor" framing dropped; sketches/ path
  instruction now scopes the no-committable-suggestion rule to changes the
  PR's linked issue does not authorize), agent-governance + home wiki
  notes, flash-and-log skill (no-hardware constraint unhooked from the
  epic — it stands while the machine is away). Self-review round widened
  the sweep to Phase-D-conditioned wording: SAFETY.md (known-gaps clause +
  stale .ino loop-order reference), naming rule (migration past tense),
  TESTING.md intro, architecture-fitness advisory-until claims (now point
  at #196), and the dashboard rule's src/generated promise (now tracked
  as #227). architecture-remediation.md keeps its epic title as dated
  history.

## 2026-07-20 — single-writer state: the two named #119 remnants closed

- lowVoltLatched now has ONE writer: [SAFETY]'s batteryCutoffUpdate() calls
  alertNotifyBatteryCutoff() ([ALERT]'s new narrow interface, which does
  the write) at the exact point it used to write the flag directly — same
  pass, same instant, alarm still starts WITH the cut. The two rule-file
  "historical example" sins are now literally historical.
- curvatureDrive() application delegate is pure: the gear-selected pivot
  cap arrives as a parameter; the composition root owns the currentGear
  read (Eco → looser cap). 17 test call sites updated mechanically with
  the faithful per-site cap value — ZERO expectation changes; suite
  27/27 green. Flash 119740 (+16 call plumbing), RAM 9800 unchanged.
- #119's struct-encapsulation proposal judged superseded: extern +
  single-writer + pure domain cores satisfies the acceptance; converting
  the remaining externs to structs would be churn against simplicity-first.
  Known residual (acknowledged, not in the issue's complaints):
  updateJoystick() reads currentGear for the joystick forward cap — an
  application-layer boundary read, single-writer respected.

## 2026-07-20 — temporary diagnostics removed from production firmware (#122)

- CALIBRATION_MODE (compile-time-false raw-throttle bypass inside the
  control path, #113 ESC-endpoint relearn — served its purpose, both ESCs
  recalibrated 2026-07-03) DELETED: DriveConfig.h const + FirmwareApp.cpp
  bypass block. If re-calibration is ever needed again, a dedicated bench
  sketch under sketches/ is the sanctioned home, not a production branch.
- telemetryDebug* X.BUS bring-up diagnostics (ex-telDbg, per-RX-byte
  counters + 16-byte snapshot + the "# XBUS rx_total=…" console dump in
  wifiDebug()) DELETED end-to-end (adapter, re-exports, print block,
  resetFirmwareState entries). They answered "does D0 see anything at
  all" during post-solder bring-up; git history keeps them. The 10 Hz CSV
  debugPrint() stream STAYS — it feeds tools/live_plot.py (production
  feature). Machine behavior unchanged; debug-console output change
  authorized by #122.

## 2026-07-20 — white-label dashboard: one BRANDING block (#136)

- Product identity (name, tagline, home-screen app title, accent trio) now
  lives in a single BRANDING config block at the top of
  dashboard/index.html; applyBranding() writes the text/meta and sets
  --brand-accent\* CSS custom properties (CSS carries the same values as
  fallbacks). Default skin is the generic DUAL TRACK CONTROL /
  VEHICLE COMMAND; "Malaki SuperTracks" is documented in the block as the
  example skin. Verified both directions with the Playwright harness:
  config-only edit produces the full Malaki look and back, all gauges and
  layout pixel-identical. The badge asset slot is the apple-touch-icon
  data URI (noted in the block); epic #81 lands the HUD badge against
  this. Remaining Malaki/Jason mentions repo-wide are operator
  documentation, which the naming rule permits.

## 2026-07-20 — dev tooling consolidated under tools/ (#123)

- All human-run tools in one home with a README index: serial
  monitors/plotters + deploy + board drawings moved from root and
  scripts/ into tools/, joining the UI tests; scripts/ deliberately
  KEEPS the CI/hook machinery (the CI-vs-human split is now the rule,
  not an accident). npm scripts expose every .mjs entry point; VS Code
  tasks, README, FILE-MAP, and structure-check allowlists updated.
  capture.py (#37) no longer exists in the tree — disposition resolved
  as already-deleted.

## 2026-07-20 — repo front door: ARCHITECTURE.md + CONTRIBUTING.md (#126)

- docs/ARCHITECTURE.md: human-facing narrative (layer shape, signal
  pipeline with the ordering invariants, safety model incl. the two
  permanent invariants and why, key decisions with DECISION-LOG receipts,
  RA4M1/ESP32-S3/GL10 split) — behavior only, no live values, per the
  authority matrix. CONTRIBUTING.md: human mirror of the agent rules
  (real-time law, placement, workflow incl. the flash-log rule, local
  check commands). README's stale [MODULE]-sections paragraph replaced
  with the composition-root description and both docs linked.

## 2026-07-20 — tests/ mirrors src/ (#195)

- Five pure-domain suites moved under tests/domain/ (battery, thermal,
  operator_input, drive, safety) so every suite sits at the path of the
  layer it tests; telemetry/ and alerts/ already mirrored. Pure git moves
  plus include-depth fix plus Makefile glob/rule paths — ZERO expectation
  changes; full suite green (27 binaries, exit 0). TESTING.md tree
  redrawn (it had already drifted: alerts/ and test_observer_encoders
  were missing) and FILE-MAP line updated.

## 2026-07-20 — semantic doc lint: the judgment half (#200)

- New `semantic-doc-lint` skill: monthly deep pass walking every wiki
  note's declared sources (#202 frontmatter is the input), sweeping for
  cross-page contradictions (authority-matrix rows as the topic list) and
  coverage gaps (recurring DECISION-LOG/PR nouns without a page); one
  issue per finding + a dated receipt line here, never inline fixes;
  safety-overclaiming docs escalate to the operator per the covenant
  triage. A scheduled workflow (semantic-lint-reminder, monthly +
  manual dispatch) opens the reminder issue when none is open. Per-PR
  advisory layer = documentation-reviewer agent in the pre-request
  self-review + the #199 receipt requirement — Phase F build items
  complete.

## 2026-07-20 — wiki lint v2: sources frontmatter + semantic-adjacent checks (#202)

- check_wiki.py extended: recursive note discovery (graph keyed by
  relative path), heading-anchor validation (GitHub slugs), mandatory
  `sources:` frontmatter on every note except README (declared paths must
  exist — a vanished source fails the lint so the note gets reconsidered;
  `sources: none` for pure navigation), duplicate-H1 detection, and a
  curated deprecated-phrase list (retired sketch name, retired gate
  filename, completed-phase framing). Selftest demonstrates every failure
  mode including recursive subdirectory discovery. All real notes gained
  honest sources frontmatter; manifest validation stays with the #199
  checker (no duplication).

## 2026-07-19 — change-impact manifest: deterministic doc-code sync (#199)

- `docs/architecture/change-impact.json` maps source areas (path prefixes)
  to knowledge pages; `scripts/check_change_impact.py` (new change-impact
  CI workflow, always-run) computes affected pages from the PR diff and
  passes only when no mapped area was touched, an affected page is updated
  in the same diff, or the PR body carries a documentation receipt
  (wiki-impact-review block or an explicit no-documentation-effect line).
  The manifest self-validates on every run (pages must exist, area
  prefixes must match something). Selftest exercises matching, sibling
  non-swallowing, receipt patterns, and real-manifest validity. The
  manifest is now the SSOT for the wiki-impact-review skill's mapping.

## 2026-07-19 — durable wiki architecture pages (#201)

- Four stable concept pages added: architecture-overview (the durable
  entry; architecture-remediation stays as dated migration history),
  application-loop (the firmwareLoop pass order incl. the two ordering
  invariants: ladders before gear select, watchdog refresh directly after
  the output gate), ports-and-adapters (link-time seams, vendor types
  never cross, the reverse telemetry-frame seam), configuration-authority
  (value kinds: config layer / adapter-owned / branding / operator /
  historical). home.md links the set; loop order verified against
  FirmwareApp.cpp before writing.

## 2026-07-19 — authority matrix: one page states which artifact wins (#198)

- `docs/wiki/authority-matrix.md` states the source-of-truth hierarchy once
  (behavior=code+tests, tunables=config layer, structure=architecture
  spec+ADRs, safety=SAFETY.md+invariant tests, operation=OPERATOR-GUIDE,
  rationale=DECISION-LOG, navigation=wiki, agent conduct=CLAUDE.md+rules+
  skills). Wiki README's stale "canonical docs (CLAUDE.md, SAFETY.md)"
  tunables claim repointed (tunables' authority is the config layer);
  CLAUDE.md Coding Rules intro links the matrix.

## 2026-07-19 — review/merge protocol amended after 52-round retrospective (#211)

- Operator decisions after PR #210 reached 34 review rounds: (1) self-review
  BEFORE bots — applicable `.claude/agents/` reviewers + a stale-reference
  sweep (names/counts/paths/claims the diff invalidates elsewhere);
  (2) merge = ONE clean bot cycle on the final commit + CI green + 0
  unresolved threads — never re-invite reviews of unchanged code (the old
  3-cycle rule re-triggered nondeterministic re-reviews and generated
  rounds); (3) scope guard — reviewer suggestions expanding a change's
  scope beyond its issue are declined into follow-up issues by default;
  (4) no derived values (counts/line numbers) in prose; (5) no hard round
  cap, but repeating finding patterns get root-caused.
- Retrospective attribution across 5 PRs / ~52 rounds: ~50% missing
  up-front spec/threat model (#210 parser), ~25% re-request ritual on
  unchanged code, ~20% derived-value + cross-reference staleness.

## 2026-07-19 — test-gate rewritten with real command parsing (#206)

- `.claude/hooks/test-gate.sh` (shell globs over the whole JSON payload) →
  `.claude/hooks/test-gate.py`: JSON + `shlex` parsing; bypass flags are
  checked ONLY among a real `git commit` invocation's own arguments.
  Fixes the observed false positives (benign `grep -n` in compound
  commands; issue/PR body prose quoting the flag names) and catches
  `git -C <path> commit -n`, which the old `"git commit"` glob missed.
  Two-attempt parse: line-oriented (newline = separator, catches multi-line
  bypasses) then whole-text (quoted heredoc commit messages legally span
  lines — the exact case the first cut blocked LIVE on its own commit);
  malformed input falls back to a fail-close TOKEN check over every line
  naming git+commit (whitespace split, same argument analysis). Bypass
  detection covers every git
  spelling: exact flags, bundled short options (`-anm` carries `-n`;
  value-taking shorts `m c C F t S` end the scan so `-mnope` passes),
  parse-options long abbreviation (`--no-v` prefix), and `--` ends option
  scanning (pathspecs). Tokenizing uses `shlex` punctuation_chars so glued
  separators cannot hide an invocation (`true;git commit -n` and
  `git commit --no-verify&&git push` were live bypasses of the exact-match
  cut — both reproduced, then sealed). The hooksPath check targets the
  commit's OWN repo (honors `git -C` / `--git-dir`).
  Wrapper/environment prefixes (`FOO=1 git`, `env git`, `sudo -u user
  git`) cannot hide the invocation — `git` is recognized in command
  position (leading assignments and executing wrappers keep it open;
  `git` as another command's data, e.g. `echo git commit -n`, does not
  block, even behind a wrapper: `env echo git commit -n`; duration
  positionals like `timeout 30 git ...` stay caught).
  Redirections are not command separators: `git 2>/dev/null commit -n`
  stays a caught invocation, trailing `> /dev/null 2>&1` on a clean
  commit passes. Both parse paths use the same command-position logic (git as data
  after a line-spanning quote stays data; a real bypass after one still
  blocks). Shell line continuations are joined first (backslash-newline), so a
  continuation-split `-n` is still caught.
  Shell -c strings (`sh -c 'git commit -n'`, incl. bundled `-lc`) are
  parsed recursively (bounded depth 5).
  Equals-form repo targeting (`--git-dir=`/`--work-tree=`) is honored,
  and a shell must itself sit in command position (`echo sh -c ...` is
  data). A wrapper option-value literally named `git` (env -u git git commit)
  is disambiguated by lookahead. Malformed and depth-capped input fails
  CLOSED (all-lines token check; the nested depth cap returns the
  conservative check, never a pass). Path-invoked git (`/usr/bin/git`, `./git`, `git.exe`) matches by
  basename; wrapper options consume a value only when the per-wrapper
  table says so (env -i does not eat the wrapped command).
  `check_hook_registration.py` carries the canonical case inventory (no
  count recorded here — it grows with the gate); structure-check allows
  `.py` under `.claude/hooks/` (hook scripts live with the config that
  registers them).

## 2026-07-16 — CLAUDE.md trimmed to ~200 lines (#197)

- Root CLAUDE.md 445 → 203 lines. Facts kept (purpose, covenant + gate,
  safety invariants, architecture boundaries, build commands, workflow
  pointers); detail moved to single homes: full file map →
  `docs/architecture/FILE-MAP.md` (verbatim; doc-sync hook message updated
  to point there); pins/UART detail → `docs/WIRING-GUIDE-V8.md` (already
  canonical there); X.BUS detail → `docs/XBUS-PROTOCOL.md`; Implementation
  Status section
  DELETED (board is SSOT) — its one untracked TODO became issue #208
  (track-speed asymmetry; its "#54 pending" line was stale, #54 closed).
- WIRING-GUIDE drift fixed while consolidating: D8 listed as free but the
  active piezo shipped on D8 in V7.11.

## 2026-07-15 — Phase E: project skills + read-only reviewer subagents (#127)

- Six project skills created under `.claude/skills/` (safety-review,
  flash-and-log, new-module, field-tune, wiki-impact-review,
  prepare-pull-request) — each skill OWNS its procedure; CLAUDE.md's ESC
  section reduced to the iron rule + a pointer (dedup per #127 acceptance).
- Four read-only reviewer subagents under `.claude/agents/` (architecture,
  safety, tests, documentation) — tool-restricted to Read/Grep/Glob
  (enforceably read-only; the caller supplies the diff); run before marking
  a PR ready.
- CLAUDE.md gained the Skills & Reviewer Agents index; agent-governance wiki
  note updated in the same PR.

## 2026-07-15 — test-gate hook wired + external-review verification (#193)

- `.claude/hooks/test-gate.sh` was dead code: `.claude/settings.json` had no
  `PreToolUse` entry, so the #47 agent-proof layer never executed (found by
  external repo review of `main@ea085d0`; TESTING.md had documented the wiring
  as if present). Registered as `PreToolUse[Bash]` and CI-guarded: new
  `scripts/check_hook_registration.py` (in `hooks-selftest.yml`) fails when a
  script in `.claude/hooks/` is unregistered, and functionally exercises the
  gate (blocks `--no-verify`/`-n`, blocks inactive `core.hooksPath`) — 7/7.
- Same review verified via API: `main` branch protection requires 1 approval
  but ZERO required status checks — all 9 CI workflows advisory (→ #196;
  already flagged 2026-07-13 as pending operator work). Wiki lint confirmed
  structural-only (links/orphans/reachability/tunable-drift) — semantic sync
  tracked in Phase F milestone (#199, #200, #202).
- Review follow-ups filed as #193–#203; Phase F milestone created.

## 2026-07-13 — Rename sweep: production sketch + bench abbreviations (#118)

- `sketches/rc_test/` → `sketches/dual_track_control/` — the production
  firmware (7 versions deep: safety ladders, watchdog, Wi-Fi dashboard) no
  longer carries a bring-up-test name. `dual_track_control` is the platform's
  white-label name (`.claude/rules/naming.md`, #136 context). Version lineage
  V7.x unchanged; FIRMWARE-UPLOAD-LOG history rows keep `rc_test`.
- Bench sketches with abbreviations not on the permitted-acronym list renamed
  to full words: `hw_diagnostic` → `hardware_diagnostic`, `telem_check` →
  `telemetry_check`, `telem_decode` → `telemetry_decode`. Acronym-compliant
  siblings (`pin_test`, `sbus_test`, `sbus_d12_test`, `usb_test`,
  `beeper_test`) keep their names.
- Follow-up in the same sweep (per the 2026-07-05 scope comment on #118):
  `live_plot_telem.py` → `live_plot_telemetry.py`, `tools/ui-test-batt.mjs`
  → `tools/ui-test-battery.mjs`, `tools/ui-test-batcolor.mjs` →
  `tools/ui-test-battery-color.mjs`; `sketches/serial2_test/` DELETED
  (operator-authorized — Nano-R4-era Serial2 collision test, obsolete on the
  UNO R4 WiFi).
- Mechanical sweep across 70 files (CI matrix, pre-commit gate, the
  tests/Makefile and FirmwareUnderTest.h include paths, scripts, docs,
  source comments);
  DECISION-LOG and FIRMWARE-UPLOAD-LOG history left untouched by design.
  Zero code changes — behavior-preserving by construction.

## 2026-07-13 — Phase D step 11b: FirmwareApp composition root — §9 COMPLETE (#189)

- The entire .ino shell moved VERBATIM into `src/application/`, split by
  responsibility: FirmwareState (mutable cross-module state + the cap
  delegates, now inline in its header for cross-TU odr-use), OperatorInput
  ([DRIVE]/[RC]/[GEAR]/[JOYSTICK]/[MIXER]), MotorOutput ([OUTPUT]),
  SafetyControl ([SAFETY]), AlertControl ([TELEMETRY]/[BEEPER]/[ALERT] —
  owns telem[]), Monitoring ([WIFI] remnant + [DEBUG] + SystemSnapshot
  construction; the ONE TU including web_page.h and arduino_secrets.h),
  and FirmwareApp.h/.cpp — the #150 MARKER + setup()/loop() bodies as
  firmwareSetup()/firmwareLoop() (watchdog refresh at its exact position).
  rc_test.ino is now a 12-line composition root; **check_ino is ACTIVE and
  passing** (the migration-window NOTE is gone).
- Two structural consequences, both verified behavior-neutral: (1) the
  AlertConfig pattern arrays became C++17 `inline` — ONE program-wide
  entity, preserving the pointer-identity semantics playback and the tests
  rely on (per-TU copies broke both); (2) config/Pins.h reaches A0/A1
  through the types.h bridge (outside-src include) since application TUs
  compile standalone; documented as interim until types.h dissolves.
- Harness: FirmwareUnderTest.h unchanged — everything resolves through the
  .ino → FirmwareApp.h chain; the pure suites now also exclude
  application/ .cpps (the infrastructure-filter precedent — application
  reaches Arduino.h via the types bridge).
- Verified: 27 host binaries green, ZERO expectation changes; compile
  flash BYTE-IDENTICAL (117796), RAM 9832 (−16, layout); fitness OK
  (4 advisory soft-size warnings, hard cap respected everywhere).
- **PHASE D §9 (steps 1–11) IS COMPLETE.** Remaining epic work: flip
  architecture-fitness/unit-tests/hooks-selftest to required checks
  (operator), the #118 rename sweep, #119/#121/#122, Phase E.

## 2026-07-13 — Phase D step 11a: the last hardware seams (#187)

- Step 11 split in two: 11a (this) builds the remaining seams so the .ino
  becomes hardware-include-free; 11b moves the shell into src/application/
  and activates check_ino. Rationale: application/ may not include
  Arduino.h/WDT.h/WiFiS3.h (dependency table), but the shims still called
  millis/micros, WDT, Serial, WiFi.status and analogReadResolution.
- New seams (all 1-line passthroughs): ports/ClockPort.h + ArduinoClock
  (clockNowMs/clockNowUs; ~13 mechanical call-site swaps),
  ports/WatchdogPort.h + WatchdogAdapter (begin/timeoutMs/refresh — the
  once-per-loop refresh invariant kept at its exact call site),
  ports/DebugConsolePort.h + SerialConsoleAdapter (begin keeps debugInit's
  verbatim boot delay(50); ready(); printLine). JoystickPort grew
  joystickInitialize() (analogReadResolution(14), same boot position);
  DashboardServicePort grew dashboardServiceRadioStatus() (WiFi.status —
  wifiDebug's last WiFiS3 touch). <WDT.h> + <WiFiS3.h> removed from the
  .ino; arduino-cli library detection re-verified via the src/ scan.
- Debug lines (banner, WDT-armed, wifiDebug x2) converted from Serial
  print-chains to snprintf-assembled whole lines — BYTE-IDENTICAL stream
  by construction (bool as 1/0, decimal counters, %02X + space per
  snapshot byte, println's CRLF via printLine). These lines are not
  test-locked; identity argued by string construction in the PR.
- Two documented mechanical substitutions (the #164 class) so 11b's moved
  code compiles without Arduino.h: constrain() → clampInt/clampFloat
  (exact macro ternary, 12 sites, types checked per site) and sbusToServo's
  map() → mapRange (ArduinoCore-API's exact long formula), both in
  src/application/RangeMath.h.
- Verified: 27 host binaries green, ZERO expectation changes (the
  control-loop suite's one-refresh-per-pass law now counts through
  watchdogRefresh() — same stub counter); compile clean — flash 117796
  (−152: line assembly replaced print-chain calls), RAM 9848 unchanged.

## 2026-07-13 — Step-11 pre-slice: config/ layer extraction (#185)

- Every `[CONFIG]` constant moved VERBATIM (values byte-identical) to
  `src/config/` per the target's grouping: BuildInfo.h (FIRMWARE_VERSION —
  the #124 SSOT gate is home-agnostic, now fires on this file), Pins.h
  (application pins; documented include-order contract — it uses the
  core's A0/A1 macros and must follow <Arduino.h>, config/ may not include
  hardware headers), InputConfig, DriveConfig (incl. CALIBRATION_MODE +
  the PIVOT_THROTTLE_TAPER static_assert), BatteryConfig, ThermalConfig,
  AlertConfig (patterns + tunables), TelemetryConfig (PRINT_INTERVAL),
  WifiConfig (AP channel), SafetyConfig (WDT_TIMEOUT_MS).
- Deliberately NOT moved: the mutable state interleaved in [CONFIG]
  (gearScale/currentGear, safety latches, thermal flags — state is not
  configuration; goes with FirmwareApp), the outCapToX/reverseCap
  delegates + Gear↔GearLevel static_assert (read globals + domain), and
  constant NAMES (SVC/OVR_*/JOY_* stay verbatim — dozens of test files
  reference them; renames are the #118 sweep's call).
- Single-homed adapter tunables stay put (X.BUS poll constants in xc/
  since #178; Wi-Fi serving tunables in network/ since #181).
- Verified: 27 host binaries green, ZERO test edits; compile
  BYTE-IDENTICAL (flash 117948, RAM 9848 — compile-time constants);
  fitness OK. [CONFIG] in the .ino is now the config include point +
  the state/delegate block.

## 2026-07-13 — Step-11 pre-slice: alerts/ layer extraction (#183)

- `[BEEPER]`/`[ALERT]` policy and sequencing moved VERBATIM to
  `src/alerts/`: AlertTypes (pattern/state/threshold structs), AlertPolicy
  (inactivity tracking, the low-voltage debounce/latch INCLUDING its own
  plausibility comparison form — deliberately NOT consolidated with
  domain/battery/VoltagePlausibility, the two diverge on NaN per the
  documented SAFETY.md gap — and the four-level priority ladder
  thermal-cut > low-V > thermal-warn > inactivity), PatternPlayer
  (one-shot + repeating, even index = ON). Time is a parameter throughout.
- The `.ino` shims keep every global and signature (mirror-globals
  precedent) — beepStart/beeperUpdate/alertInit/alertUpdate fold state
  through the structs per call; the `alertOutputSet(horn || pattern ||
  alarm)` OR stays in the shim; patterns + tunables stay `[CONFIG]`-owned
  until the config/ pre-slice. ZERO expectation changes (test_alerts.cpp
  characterization is law); new pure suite tests/alerts/ (6 cases:
  priority ladder, latch debounce/sticky/grace/implausible, inactivity,
  both players).
- Accepted micro-delta (same class as the #158 entry): the one-shot
  transition previously read millis() twice (compare, then phase
  re-anchor); the pure step takes one nowMs. Host-identical (stub time
  constant within a call); ≤1 ms phase re-anchor difference per transition
  on hardware.
- DEFERRED with reasoning (own issues when prioritized): lowVoltLatched
  ownership (#119 target: SafetyDecision.alarmRequested — [SAFETY] still
  borrows the global) and snapshot-consuming alert presentation (#132
  deferral — alertUpdate keeps reading telem[] directly).
- Verified: 27 host binaries green; compile clean — flash 117980 (+320,
  shim fold/unfold), RAM 9848 unchanged.

## 2026-07-13 — Phase D step 10 final slice: infrastructure/network/ (#181)

- The `[WIFI]` serving machine moved to `src/infrastructure/network/`
  behind `ports/DashboardServicePort.h`: `WifiService` (AP bring-up +
  FNV-1a ETag #109 + shared serving state, extern for the harness),
  `DashboardServer` (bounded request read/route, /data one-shot, ETag/304
  path, incremental one-chunk-per-pass page transfer #69 with 0-byte-write
  aborts), `SseStream` (SSE upgrade with unconditional prior-socket reap
  #77, single-write heartbeat+data frame #54). All #69/#54/#77 invariants
  moved line-for-line; SSE branch mechanically restructured from a nested
  else into early returns (same predicates, same order).
- **Dependency inversion:** `ports/TelemetryFrameSource.h` is a REVERSE
  link-time seam — declared in ports/, implemented by the .ino (delegates
  to buildTelemJson), called by the network layer where wifiUpdate used to
  call buildTelemJson. Infrastructure never includes application/ or
  telemetry/; it ships bytes.
- Identity stays sketch-owned and is passed at initialize: credentials
  (arduino_secrets.h never leaves the .ino), WIFI_AP_CHANNEL, and the
  INDEX_HTML page pointer. The four serving tunables (SSE_INTERVAL_MS 200,
  SSE_FRAME_CAP 448, WIFI_PAGE_CHUNK 1024, WIFI_MODEM_TIMEOUT_MS 50) moved
  from [CONFIG] into WifiService.h with the machine — values unchanged,
  single home (the target config/ layer re-homes them later). The ready
  beep stays application-side (initialize returns AP-up); the beep now
  fires ~1 ms later at boot (after the banner prints) — non-observable.
- `wifiMode()`, `wifiDebug()` (reads adapter state via extern) and
  `wifiSeq` stay in the .ino. `pagePtr` renamed `pagePointer` on move
  (naming.md). Verified: 26/26 host binaries green, ZERO expectation
  changes; flash 117660 (+64), RAM 9848 (+12: the page-pointer global —
  layout, not behavior). Step 10 COMPLETE — only step 11 FirmwareApp
  remains in Phase D's §9 sequence.

## 2026-07-13 — SystemSnapshot: observers read one immutable per-cycle struct (#132)

- `src/application/SystemSnapshot.h` (first `application/` file — the #150
  check_ino marker stays dormant until FirmwareApp.h): nowMs, RC servo-µs
  input view + failsafe/lost, raw joystick pair, outL/outR, gear + override
  mode, the five safety flags, and per-ESC `EscTelem` copies. Deliberately
  does NOT include types.h (which pulls Arduino.h) so the pure suites stay
  stub-free — gear is carried as a plain int.
- `telemetry/JsonEncoder` + `telemetry/CsvEncoder`: buildTelemJson()'s and
  debugPrint()'s exact format strings moved VERBATIM; both take
  `const SystemSnapshot&` and use the TelemetryScaling encode helpers —
  killing debugPrint's inline lroundf duplication (same math, the #121
  second half). wifiSeq stays [WIFI]-owned and is passed in.
- The .ino shims keep names/signatures and build the snapshot AT THE
  ORIGINAL OBSERVATION POINTS (buildTelemJson reads millis() exactly where
  it used to) for exact timing parity; the once-per-cycle build moves into
  FirmwareApp at step 11. Alert presentation deferred to the alerts/
  extraction with reasoning ([ALERT] owns lowVoltLatched — policy, not a
  read-only observer; documented on issue #132).
- NEW pure suite tests/telemetry/test_observer_encoders.cpp locks the EXACT
  JSON/CSV bytes (previously untested); 26 host binaries green. Compile
  clean — flash 117580 (+224: the snapshot copy at the observation points;
  emitted bytes identical), RAM 9836 unchanged.

## 2026-07-13 — Phase D step 10 slice 4: TelemetrySource + XbusTelemetryAdapter (#178)

- `ports/TelemetrySource.h` now owns the `EscTelem` struct (moved verbatim
  from `types.h`; types.h re-includes the port so every consumer still
  resolves it) + `telemetrySourceInitialize()` /
  `telemetrySourceUpdate(EscTelem*, escCount)`. The CALLER keeps owning the
  `telem[]` array — [ALERT], [SAFETY], the dashboard JSON and debug all read
  it sketch-side; the adapter owns only the bus + poll state.
- `infrastructure/xc/XbusTelemetryAdapter.h/.cpp` (first `xc/` folder): the
  whole 0x10 poller moved VERBATIM — protocol constants, checksum, request
  framing, echo-skipping parse, EMA fold, alternating poll state machine,
  per-ESC staleness watchdog, `Serial1.begin`. The header is host-pure
  (constants + inline scaling + extern state for the harness).
- Register DECODE + `emaFold` moved from `telemetry/TelemetryScaling.h`
  into the adapter header — forced by the dependency table (infrastructure/
  may not include telemetry/) and semantically right (decode = X.BUS
  register semantics). The ×10 wire ENCODE stays in TelemetryScaling.h.
  Each function still has exactly ONE implementation.
- Naming fixed on move (naming.md applies to MOVED code): `telemEsc` →
  `telemetryPolledEscIndex`, `telemWaiting` → `telemetryAwaitingResponse`,
  `telRx/telRxLen` → `telemetryReceiveBuffer/Length`, `telDbg*` →
  `telemetryDebug*`, `telemSendRequest` → `telemetrySendReadRequest`,
  `TELEM_*` → `TELEMETRY_*`, `XBUS_HDR_*` → `XBUS_HEADER_*`, `REG_*` →
  `REGISTER_*` full words. EscTelem FIELD names unchanged (dozens of
  untouched consumers — mass-rename prohibited). Tests updated mechanically;
  `telemUpdate()` stays as the .ino shim (loop call site + suite entry
  unchanged). `telDbgPrintPrevMs` found to be write-never-read (bring-up
  leftover) — moved as-is, no behavior question.
- Verified: all 25 host binaries green, ZERO expectation changes; compile
  clean — flash 117324 (−32 vs 117356), RAM 9836 (+4; layout). Remaining
  step-10 adapter: Wi-Fi/network; watchdog + clock land with FirmwareApp
  (step 11).

## 2026-07-13 — Phase D step 10 slice 3: RcInputPort + SbusReceiverAdapter (#176)

- `ports/RcInputPort.h` defines the RC input contract in domain types:
  `RcFrame {int16_t channels[16]; bool failsafe; bool lostFrame;}` +
  `rcInputInitialize()` / `rcInputReadFrame(RcFrame*)`. The bfs vendor
  S.BUS type never crosses the port — first slice to translate a vendor
  type at the boundary rather than pass it through.
- `infrastructure/radiolink/SbusReceiverAdapter.cpp` owns `UART
  sbusUart(11, 12)` (SCI0 — the not-`Serial2` collision detail) and
  `bfs::SbusRx` (moved from the `.ino`); on `Read()` success it copies 16
  channels + failsafe/lost_frame into the caller's `RcFrame`. First
  non-`arduino/` infrastructure folder (vendor-specific: radiolink).
- The `.ino`'s `bfs::SbusData sbusData` global became `RcFrame rcFrame`;
  every consumer renamed mechanically (`.ch[` → `.channels[`,
  `.lost_frame` → `.lostFrame`). The loop() read block keeps its exact
  freshness semantics (`sbusLastFrame = now` on frame, `SBUS_TIMEOUT`
  staleness unchanged). `#include "sbus.h"` moved to the adapter
  (empirically verified — arduino-cli library detection scans src/).
- Harness: `feedSbusFrame()` now scripts through `rcInputReadFrame()`
  exactly like loop(); `resetFirmwareState()` resets `rcFrame` and
  re-creates the extern `sbusRx` (parser residue = power-cycle
  equivalence). Stub sbus.h frame queue is global, so scripting is
  unchanged.
- Verified: all 25 host binaries green, ZERO expectation changes; compile
  clean — flash 117356 (+52), RAM 9832 (+4; linkage/layout of the moved
  objects, not behavior). Remaining step-10 adapters: X.BUS telemetry
  poller, Wi-Fi/network; watchdog + clock land with FirmwareApp (step 11).

## 2026-07-13 — Phase D step 10 slice 2: JoystickPort + AlertOutputPort adapters (#174)

- `ports/JoystickPort.h` + `infrastructure/arduino/AdcJoystickAdapter.cpp`:
  the ADC conditioning sequence moved VERBATIM (discard-read → 100 µs mux
  settle → real read, Y then X — hardware timing at the 100 Hz joystick
  cache cadence, non-blocking budget unchanged). `updateJoystick()` keeps
  the cadence guard, deadband/expo/gain pipeline and cachedJoy writes.
- `ports/AlertOutputPort.h` + `infrastructure/arduino/PiezoAdapter.cpp`:
  pinMode+LOW at initialize, one digitalWrite per set. The horn/pattern/
  alarm OR-priority stays in `[BEEPER]` (alert policy, not hardware —
  destined for the alerts/ layer later); `beeperUpdate()` computes the
  same boolean and calls `alertOutputSet(...)`.
- Verified: all 25 host binaries green, zero expectation changes (stub
  analogRead/GPIO captures now reached through the adapters); compile
  clean — flash 117304 (+68 vs 117236), RAM 9828 (+4: the piezo pin int).
  Remaining step-10 adapters: S.BUS receiver, X.BUS telemetry poller,
  Wi-Fi/network, watchdog + clock (port-less in the target — land with the
  FirmwareApp composition root, step 11).

## 2026-07-13 — Phase D step 10 slice 1: EscOutputPort + PwmEscAdapter (#172)

- First infrastructure slice: `ports/EscOutputPort.h` (link-time seam per
  #130 — free functions, no virtuals) + `infrastructure/arduino/
  PwmEscAdapter.cpp`, which now owns the `Servo escL, escR` objects (moved
  from the `.ino`) and remembers the pins passed at
  `escOutputInitialize(PIN_ESC_L, PIN_ESC_R)`.
- Behavior boundaries: the `constrain(SVMIN, SVMAX)` clamp and the
  `outL`/`outR` globals stay in the `.ino` (application-visible state read
  by buildTelemJson and the OutputGate shim); only the writeMicroseconds /
  attach / detach calls go through the port — same call sites, same order.
- Harness: pure suites now compile `SKETCH_PURE_CPPS` (infrastructure
  filtered out — hardware includes need the stubs the pure suites
  deliberately exclude); firmware suites compile everything (stub Servo.h
  captures unchanged). `FirmwareUnderTest.h` reaches the moved Servo
  objects via extern declarations. The adapter includes `<Arduino.h>`
  before `<Servo.h>` (the stub Servo.h uses millis()).
- Verified: all 25 host binaries green, zero expectation changes; compile
  clean — flash 117236 (+76), RAM 9824 (+12: the adapter's two remembered
  pin ints — first RAM delta of the series; memory layout, not behavior).
  architecture-fitness exercises ports/ + infrastructure/ layer rules for
  the first time: OK. Remaining adapters (joystick ADC, S.BUS, X.BUS,
  Wi-Fi, piezo, watchdog, clock) follow in later slices or with the
  FirmwareApp composition root (step 11).

## 2026-07-13 — Phase D step 9: OutputGate extracted to src/domain/safety/ (#170)

- `outputUpdate()`'s fail-safe state machine (#88/#65) moved VERBATIM to
  `src/domain/safety/OutputGate.h/.cpp` as `outputGateStep(OutputGateState&,
  driveAllowed, commanded, current, nowMs, neutralPulse, holdDurationMs) →
  OutputGateAction {attach, write, pulses, detach}`. The pure machine owns
  the ACTIVE/HOLD/CUT transitions and the exact float ease-out ramp
  (zero-duration guard, >1 clamp, `rampFrom + (int)((neutral−rampFrom)·t)`);
  the shim executes the hardware actions in the original order — attach,
  write, detach — so the ESCs still see the final neutral write before
  losing signal.
- Behavior laws carried and unit-locked: ease-out starts from the LIVE
  outputs snapshot; detach only after the ramp completes; resume-from-CUT
  re-attaches while recovery mid-HOLD does NOT (ESCs were never detached);
  CUT emits nothing. OutState↔OutputGateMode value correspondence
  static_asserted in the shim (the GearLevel↔Gear pattern).
- SVC and CUTOFF_HOLD_MS stay `[CONFIG]`, passed as parameters; millis()
  read by the shim. Gate globals (outState/outHoldMs/rampFromL/R) stay in
  the .ino, mirrored via the state struct — harness resets untouched.
- Verified: all 25 host binaries green, zero expectation changes (new
  `tests/safety/test_output_gate_domain.cpp`, 5 cases); compile clean —
  flash 117160 (+160 vs 117000), RAM unchanged 9812. This completes the
  DOMAIN extractions (§9 steps 1–9); steps 10–11 are infrastructure
  adapters + the FirmwareApp composition root.

## 2026-07-12 — Phase D step 8: SafetySupervisor extracted to src/domain/safety/ (#168)

- The inline drive gate in `loop()` — `driveAllowed = sbusValid &&
  (batteryOkConfirmed || bootGraceElapsed) && !batteryCutoffLatched &&
  !tempCutActive` — moved to `src/domain/safety/SafetySupervisor.h/.cpp` as
  `safetySupervisorDecide(SafetyInputs) → SafetyDecision {driveAllowed,
  FailsafeReason}`. The early-return shape is provably identical to the &&
  chain (unit-locked by an exhaustive 32-input equivalence case); the
  reason priority mirrors the chain order (RC_STALE > BOOT_GATE >
  BATTERY_CUTOFF > THERMAL_CUT).
- The fail-open boot gate (#65 law — a dead X.BUS never permanently
  disables driving) moved verbatim as `batteryConfirmed ||
  bootGraceElapsed`; the call site computes the millis()-based grace check
  and passes a bool (time is a parameter).
- The `FailsafeReason` is new surface consumed by the OutputGate (step 9)
  and SystemSnapshot (#132) steps; today's call site uses only
  `driveAllowed` (documented at the call site). `outputUpdate()`'s
  ease-to-neutral state machine is step 9 — untouched here.
- Verified: all 24 host binaries green, zero expectation changes; compile
  clean — flash 117000 (+112 vs 116888, cross-TU call + struct), RAM
  unchanged 9812. No bench check applicable (pure move).

## 2026-07-12 — Phase D step 7: GearPolicy + CommandMixer extracted to src/domain/drive/ (#166)

- `updateGear()`'s decision tree moved to `GearPolicy.h/.cpp` as
  `gearPolicySelect(gearPulse, rcValid, forceEco, parameters) →
  GearSelection` — RC-invalid failsafe, strict CH4 thresholds, forceEco
  (battery Eco lock OR thermal Eco) overriding last, verbatim. The
  `reverseCap()`/`outCapToX()` helpers became parameter-visible
  `reverseCapForGear()`/`trackCapToAxisDomain()`. The `.ino` shims own the
  boundary reads (sbus CH4, Eco forces) and mirror `gearScale`/`currentGear`.
- `maxOppose()` (#90) moved keeping its name/signature (definition deleted
  from the `.ino`, like `expoCurve` in #162); `mixCommands()` delegates to
  `mixAxisCommands()` with the `OVR_LO`/`OVR_HI` thresholds as parameters —
  Mode 2's exact-zero rcActive compare preserved verbatim (locked law).
- Domain `GearLevel` enum (GEAR_ECO/NORMAL/BOOST = 0/1/2) mirrors types.h's
  `Gear` values; the correspondence is `static_assert`ed in the `.ino`, so
  the shim casts are compile-time-proven and the SSE gear encoding is
  untouched. New `AxisCommand` (layout-identical to `DriveCommand`) joins
  `DriveTypes.h`.
- Verified: all 23 host binaries green with zero expectation changes (new
  `tests/drive/test_gear_mixer_domain.cpp`: threshold edges, failsafe and
  forceEco dominance, per-gear reverse caps, cap-domain conversion,
  maxOppose truth table, all three mixer modes incl. the exact-zero law).
  Compile clean — flash 116920 (+136 vs 116784, cross-TU calls), RAM
  unchanged 9812. Step-6 domain test scale constants renamed
  (GEAR_ECO→GEAR_ECO_SCALE) to clear the new enum's names — test-file
  naming only, no expectation changes.

## 2026-07-12 — Phase D step 6: CurvatureDrive extracted to src/domain/drive/ (#164)

- The propulsion-path core `curvatureDrive()` (`[DRIVE]`) moved to
  `src/domain/drive/CurvatureDrive.h/.cpp` as
  `curvatureDriveStep(xSpeed, zRotation, gearScale, CurvatureParameters)`
  over `DriveTypes.h` (`TrackCommand` — layout-identical to WheelSpeeds;
  `CurvatureParameters` carrying pivotCap/taper/blend band/turnTrackCap).
  The algorithm commentary (#72/#86/#96/#114 laws) moved with the code.
- Exactly two mechanical substitutions, both float-semantics-identical:
  Arduino's `constrain()` macro expanded as `clampFloat()` (same ternary),
  and tunables read from the parameters struct.
- **State-ownership sin fixed structurally**: `curvatureDrive()` was the
  documented example of a hidden global read (`currentGear` behind the
  parameter list). The `.ino` delegate now owns the gear read visibly —
  `pivotCap = (currentGear == GEAR_LOW) ? PIVOT_SPEED_CAP_LOW :
  PIVOT_SPEED_CAP` — and passes it in. Same value, same pass. The delegate
  keeps the exact `curvatureDrive(x, z, gearScale) -> WheelSpeeds`
  signature, so all 17 test references and both call sites are unchanged.
- Verified: all 22 host binaries green with ZERO expectation changes — the
  characterization suite's exact float32 expectations for pivot caps, the
  smoothstep blend, the faded-ceiling desaturation, and reverse-steering
  consistency pass unchanged against the extracted implementation. New
  `tests/drive/` pure suite (7 cases) locks the laws at the unit level.
  Compile clean — flash 116784 (+48 vs 116736, cross-TU call), RAM
  unchanged 9812. No bench check applicable (pure move; bench
  re-verification of the whole series remains queued for hardware return).

## 2026-07-12 — Phase D step 5: ExpoCurve + DeadbandPolicy extracted to src/domain/operator_input/ (#162)

- `expoCurve()` moved from `[JOYSTICK]` to
  `src/domain/operator_input/ExpoCurve.h/.cpp` with the SAME name and
  signature — the `.ino` definition was removed and every call site
  (including the characterization tests) resolves to the domain
  implementation directly; weights stay `[CONFIG]` parameters.
- `rcDeadband()` / `joyDeadband()` now delegate to one parameterized
  `centerSnapDeadband(value, center, width)` in `DeadbandPolicy.h/.cpp` —
  the two originals were the identical comparison with different constants.
  Arduino's `abs()` macro is expanded manually in the domain (equivalent
  for every reachable servo-µs/ADC value).
- Deliberately deferred: `InputNormalization` (entangled with
  `currentGear`/`reverseCap()` → extracts with GearPolicy/CommandMixer) and
  `sbusToServo()` (S.BUS protocol mapping on Arduino `map()` — reimplementing
  `map()` risks integer-rounding drift; infrastructure adapter territory).
- Verified: all 21 host binaries green (new `tests/operator_input/` suite:
  exact [CONFIG] weight-pair math at 0/0.5/1, magnitude-only symmetry,
  inclusive band edges for both RC and joystick parameterizations), zero
  expectation changes; compile clean — flash 116736 (+48 vs 116688,
  cross-TU calls), RAM unchanged 9812. No bench check applicable.

## 2026-07-12 — Phase D step 4: TelemetryScaling extracted to src/telemetry/ (#160)

- The X.BUS register decode math from `[TELEMETRY]` `telemApplyReg()`
  (VBAT ×0.1 V; IBUS ×0.1 A signed; MSPEED signed electrical Hz; TESC/TMOT
  low byte − 40 °C; the EMA fold) and the compact wire encode from `[WIFI]`
  `buildTelemJson()` (volts/amps → deci-integers via `lroundf(v*10)`,
  temperatures → whole °C, electrical Hz ×30 → dashboard RPM) moved to
  header-only `src/telemetry/TelemetryScaling.h` — first file in the
  observer `telemetry/` layer; the two `.ino` functions stay as callers
  delegating each expression. Observable behavior and wire format preserved
  exactly.
- Verified: all 20 host binaries green (new `tests/telemetry/` pure suite:
  register signedness, low-byte temperature mask, EMA seeding, half-away-
  from-zero deci rounding), zero expectation changes; compile clean — flash
  116688 BYTE-IDENTICAL to pre-change (inline header functions), RAM 9812
  unchanged. No bench check applicable (pure move).

## 2026-07-12 — Phase D step 3: thermal ladder extracted to src/domain/thermal/ (#158)

- `tempStageUpdate()` / `hottestMotorTemp()` / `thermalUpdate()` staging
  logic moved to `src/domain/thermal/` as `thermalStageStep()`
  (ThermalHysteresis), `hottestPlausibleTemperature()` +
  `thermalDeratingStep()` (ThermalDerating) over ThermalTypes structs —
  observable staging behavior preserved exactly; the shim-boundary deltas
  and one provably output-identical initialization change are itemized
  below for the audit trail.
  Thresholds/bounds stay in `[CONFIG]`, passed as parameters. The sketch
  keeps all three functions as delegate shims — all 28 test references
  unchanged. The firmware's three independent stage bools kept verbatim;
  the target glossary's ThermalStage enum is a later consolidation.
- Boundary work stays in the shims: clock read (time is a parameter),
  telem[]→ThermalReading flattening (per-ESC validity mirrored to both its
  sensors — comparison-identical to the original per-ESC loop), stage-global
  mirroring, and BEEP_THERM_RESTORED queued on the domain's cut-released
  return ([BEEPER] stays application-side, as with lowVoltLatched in #154).
- Same accepted non-observable delta as #154 (logged precedent): the shim
  reads `millis()` and builds the reading array unconditionally where the
  original early-returned on telemetry dropout. `hot` initialized to 0.0f
  (the #155-round lesson: never pass a possibly-unwritten out-param).
- New pure-domain suite `tests/thermal/test_thermal_domain.cpp` (8 cases)
  locks: trip at exactly since+debounce, timer reset on drop-back, the
  hysteresis HOLD inside the on/off gap incl. exactly-OFF (behavior law),
  immediate release below OFF, plausible-hottest selection with inclusive
  band edges and unwritten out-param on reject, dropout-holds-every-stage
  (timers too), cut-released edge fires exactly once, stage independence at
  86 C. Makefile: thermal/ glob + no-stubs rule mirroring battery/.
- Verified: full host suite green before/after, zero expectation changes;
  compile clean — flash 116688 (+200 vs 116488), RAM unchanged 9812. No
  bench check applicable (pure move).
- Review fix (Copilot): the hottest-selection running max now starts at
  `plausibleMinC` instead of the original `-1000.0f` sentinel — provably
  output-identical for every input (accepted readings are all >= minC), but
  correct for any parameter range now that the bounds are parameters (the
  sentinel was only safe with the fixed -20 °C constant). Unit-locked with a
  below-sentinel-band test case.

## 2026-07-12 — Documentation-sync hook + autonomous merge protocol (#156)

- **Documentation-sync hook** (operator directive): `PostToolUse` hook in
  `.claude/settings.json` runs `scripts/documentation_sync_hook.py` after
  every Edit/Write. When the file matches the watched paths
  (sketches/**/*.ino|.h|.cpp, dashboard/index.html, scripts/*.py,
  .github/workflows/*.yml, tests/** — excluding web_page.h,
  arduino_secrets.h, src/generated/, tests/build/, vendor/), it injects a
  once-per-session prompt telling the agent to verify docs/wiki +
  architecture docs + CLAUDE.md file map against the change in the same PR.
  Selftest (10 checks) wired to new `hooks-selftest.yml` CI.
- **Mechanism finding:** PostToolUse hooks that print plain stdout never
  reach the model (transcript-only) — the three pre-existing prompt-style
  PostToolUse hooks in `.claude/settings.json` are silently inert. The new
  hook uses the working `hookSpecificOutput.additionalContext` JSON form.
  Converting the old hooks is left to the operator (they would start firing
  for the first time).
- **Autonomous merge protocol** (operator, same day): after a PR's review
  rounds are resolved, 3 consecutive clean Copilot request→no-comments
  cycles (~5 min apart) + CI green + zero unresolved threads ⇒ the agent
  merges (squash, admin bypass of the 1-approval rule — bots cannot approve)
  and continues to the next issue. First use: PR #155 (c595722).
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

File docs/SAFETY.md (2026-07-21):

# Safety Invariants (#131)

Properties of the propulsion path that must **always** hold — for any input
combination, in any override mode, under any injected fault. Each invariant is
executable: it has a host test in `tests/invariants/` that drives the real
firmware (see `docs/TESTING.md`) and runs in CI with the #47 characterization
suite (the `unit-tests` check — the layer that binds every contributor).
Locally, `.githooks/pre-commit` hard-blocks red commits once activated in the
clone (`git config core.hooksPath .githooks`, see docs/TESTING.md).

This registry lists the invariants from issue
[#131](https://github.com/boulaajaj/Arduino-DiggerSetup/issues/131) verbatim,
with scope clarifications added in parentheses where the issue wording alone
could over-promise. The
human-facing safety-model narrative (battery ladder, thermal stages, output
gate, watchdog) will live in `docs/ARCHITECTURE.md` when #126 lands; this file
stays the single list the tests are named after.

## Motivating incident (#69)

On 2026-06-20 a blocking ~33 KB Wi-Fi page send froze `loop()` for 1–2 s while
the hardware-timed servo PWM **held the last throttle** — the machine kept
driving, uncommanded, under load. The fix was V7.13 (250 ms watchdog +
incremental serving; see `docs/DECISION-LOG.md` entries 2026-06-20 and
2026-06-21, and ADR-0001). This suite exists so that class of failure is a
**failing test, not a field discovery**.
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

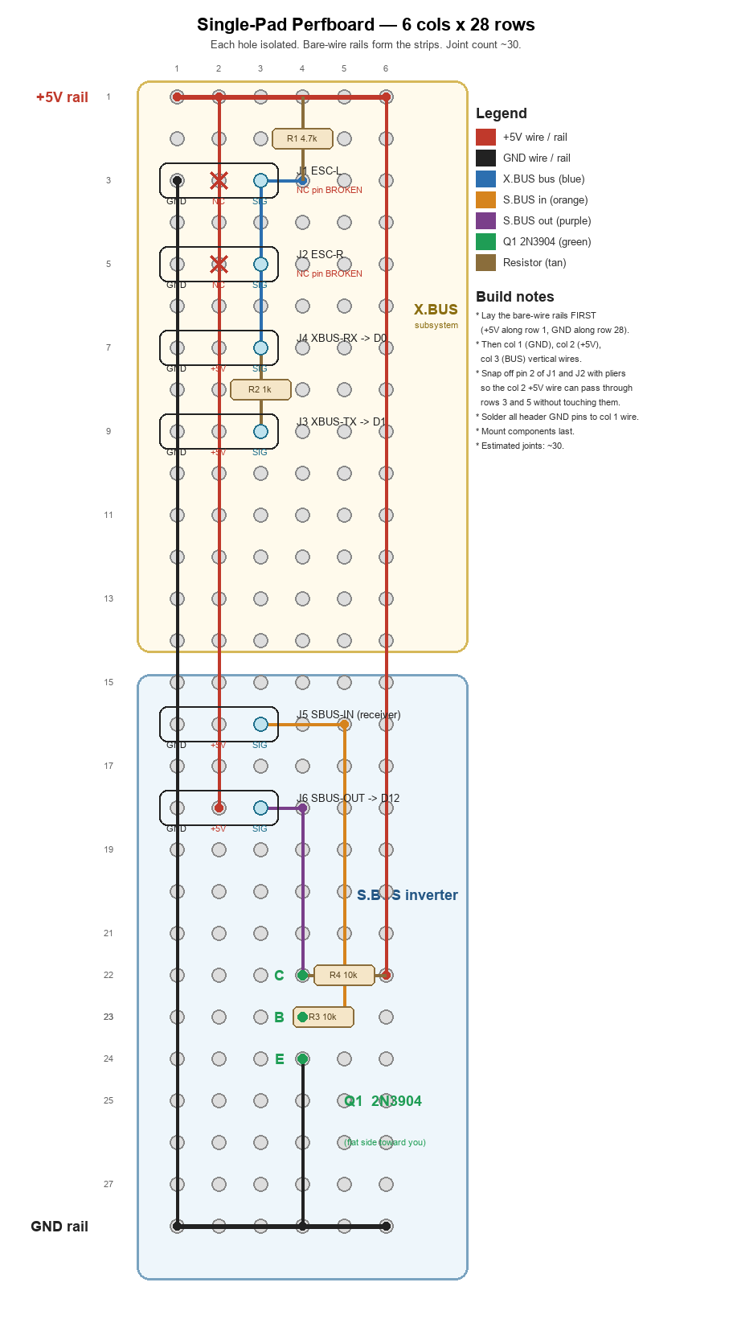
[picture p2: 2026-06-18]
docs/interface-board-singlepad-layout.png

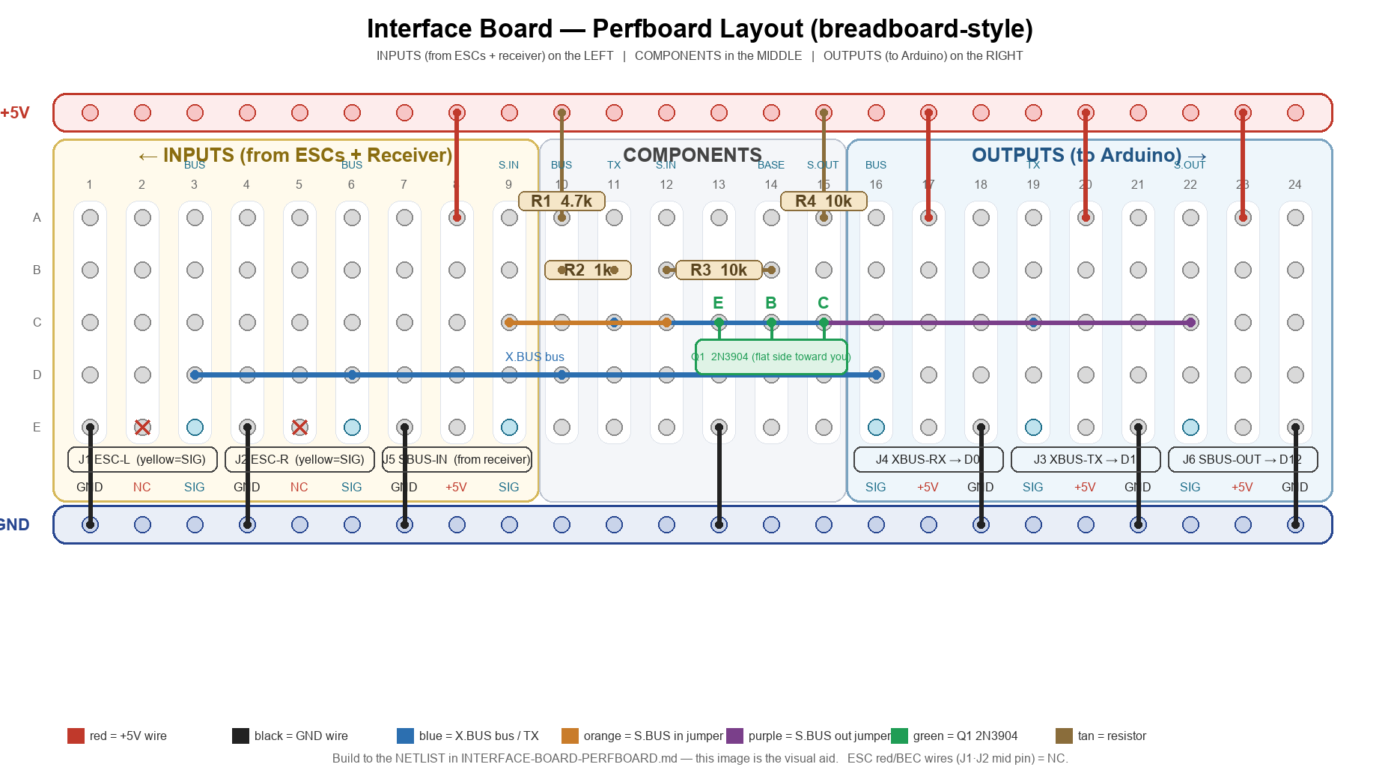
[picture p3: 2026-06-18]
docs/interface-board-perfboard-layout.png

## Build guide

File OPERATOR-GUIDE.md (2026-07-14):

# Digger Control System — Operator Guide

## For Jason (RC remote) and Malaki (joystick)

This machine has **two ways to drive it**: an RC remote controller and a
joystick. An Arduino UNO R4 WiFi sits in the middle and
decides which input controls the tracks based on a 3-position switch on
the remote.

---

## How It Works

The machine has **two tracks** (left and right), each driven by its own
motor and ESC. The Arduino reads signals from both the RC remote and the
joystick, picks the right one based on the override switch, and sends
smoothed commands to the motors.

```text
  Jason's RC Remote ──────┐
                          ├──> Arduino ──> Left Track Motor
  Malaki's Joystick ──────┘           ──> Right Track Motor
```

---

## The 3 Modes (Override Switch on RC Remote)

The 3-position switch on Jason's remote controls who drives:

### Mode 1 — Remote Only (switch DOWN)

- **Jason** has full control of both tracks
- **Malaki's** joystick is completely ignored
- Use this when Jason needs precise, solo control

### Mode 2 — Joystick with RC Override (switch MIDDLE)

- **Malaki** drives using the joystick
- **Jason** can take over instantly by moving his sticks
- As soon as Jason releases his sticks back to center, Malaki has
  control again
- This is the normal operating mode — Malaki drives, Jason supervises

### Mode 3 — Blended 50/50 (switch UP)

- **Both** inputs are active at the same time
- The output is a 50/50 mix of Jason's remote and Malaki's joystick
- Useful when both operators need to coordinate together
- Jason's input won't fully override Malaki's — they share control

---

## Controls

### Jason's RC Remote

- **Left stick / Right stick:** Controls left and right tracks directly
  (the transmitter handles the mixing internally)
- **3-position switch (CH5):** Selects the mode (see above)
- Moving any stick takes priority over the joystick in Mode 2

### Malaki's Joystick

- **Push forward:** Both tracks forward (machine drives straight ahead)
- **Pull back:** Both tracks backward
- **Push right:** Left track forward + right track backward (turns right)
- **Push left:** Right track forward + left track backward (turns left)
- **Diagonal:** Combines forward/backward with turning

---

## Safety Features

### Gear Speed Caps (the safety throttle)

The motors are very powerful, so top speed is capped by the **gear switch
(CH4)** on the remote. The cap applies to BOTH the remote and the joystick:

| Gear | Straight-line speed | Reverse | Pivot (spin in place) |
| ---- | --- | --- | --- |
| **Eco** | 65% | 55% | 72.5% |
| **Normal** | 80% | 55% | 60% |
| **Boost** | 100% | 65% | 60% |

The "straight-line speed" is the cap on **average** track speed. In a turn,
Eco and Normal let the outer track speed up to keep the machine moving, so it
**doesn't bog down in corners** (Eco keeps ~35% headroom, Normal ~20%). Boost
is already flat-out, so it has no extra turning headroom.

Full stick travel is always usable — the cap just sets the maximum the stick
maps to, so no stick movement is wasted. **Start in Eco.** Eco deliberately
gives reverse and pivoting a little extra authority so the machine can still
maneuver in tight spaces at low speed.

### Smooth Acceleration

The machine won't lurch when a stick is pushed quickly — but the smoothing is
now handled **inside the GL10 ESCs** (their internal FOC ramps the motor),
not by a delay in the Arduino. The stick command is sent straight through, so
releasing the stick stops the machine promptly — important for avoiding
obstacles. (The old Arduino-side ramp was removed when the GL10 ESCs took over
that job.)

### RC Signal Loss Protection

If the Arduino loses the RC signal for about a tenth of a second (remote turned
off, out of range, etc.), both tracks are held at neutral. A hardware watchdog
also resets the controller — and drops the ESCs to neutral — if the firmware
ever stalls.

### Jason Always Has Override

In Mode 2, Jason can always take control instantly by moving his sticks.
This is a safety net — if Malaki needs help or the machine is heading
somewhere it shouldn't, Jason can intervene immediately.

---

## Quick Reference

| What | How |
| --- | ----- |
| Malaki drives alone | Switch to Mode 2 (middle), Jason hands off |
| Jason drives alone | Switch to Mode 1 (down) |
| Both drive together | Switch to Mode 3 (up) |
| Emergency stop | Jason: sticks to center in any mode |
| Max speed | Set by gear: Eco 65% / Normal 80% / Boost 100% |
| Smoothing | Handled inside the GL10 ESCs (FOC) |
| Signal-loss stop | Tracks neutral after ~0.1 s of lost RC |

---

## Beep Meanings (the D8 buzzer)

The digger has one buzzer that makes different sounds. **Count the beeps** —
each pattern means one thing, and nothing else.

| What you hear | Meaning | What to do |
| --- | --- | --- |
| **Two short beeps** (once, right after power-on) | Wi-Fi telemetry is up | Connect your phone to `Digger-Telemetry` to see the dashboard (optional) |
| **Steady tone** (only while held) | Someone is pressing the horn button on the RC remote | Nothing — that's the horn |
| **One long beep, every 2 seconds** | The **RC remote has been turned off for over a minute** | **Unplug the LiPo batteries.** Left plugged in, they slowly drain and can be ruined within a week or two |
| **Three fast chirps, over and over, won't stop** | A **battery is low** (below 10.5 V) | **Stop and charge the batteries.** At this stage it is a warning — the motors keep running. If a battery keeps dropping, the firmware protects the packs in stages: below 10.8 V it locks the digger into Eco (slower), and below 10.0 V it **stops the motors entirely** (the chirping continues so the cutoff is never silent). The alarm and the cutoff will NOT reset until you unplug and re-power the digger. |

**Notes:**

- The low-battery alarm is *latched* on purpose — once it starts, it keeps going
  even if the voltage bounces back up, so you can't miss it. Power-cycle to reset
  it after charging.
- The low-battery alarm checks **both** batteries and sounds for the weaker one.
- It only triggers when both batteries are reporting — if one isn't plugged in
  yet, it stays quiet (so it won't false-alarm while you're powering up).
- The alarms themselves are **sound only** — but the firmware's separate staged
  battery protection (#65) does act on the motors: Eco lock below 10.8 V, full
  motor cutoff below 10.0 V (latched until power-cycle).

---

## Adjusting Settings

These values can be changed in the Arduino sketch
(`sketches/dual_track_control/dual_track_control.ino`) by editing the tuning constants at the
top of the file:

| Setting | Current Value | What It Does |
| --- | --- | --- |
| `GEAR_LOW_SCALE` | 0.65 | Eco average-speed cap (fraction of full) |
| `GEAR_MID_SCALE` | 0.80 | Normal average-speed cap |
| `GEAR_HIGH_SCALE` | 1.00 | Boost average-speed cap |
| `REVERSE_CAP_STD` | 0.55 | Reverse cap in Eco/Normal (true % after the 2026-07-03 ESC recalibration) |
| `REVERSE_CAP_BOOST` | 0.65 | Reverse cap in Boost |
| `PIVOT_SPEED_CAP` | 0.60 | Spin-in-place (pivot) cap |
| `PIVOT_BLEND_END` | 0.55 | Throttle where pivot fully blends into drive (wider = gentler hand-off) |
| `PIVOT_THROTTLE_TAPER` | 0.70 | How strongly steering holds the pivot when you feed throttle (higher = pivot holds longer / exits into an arc more gradually; 0 = old surge behavior) |
| `JOY_THROTTLE_GAIN` | 1.40 | Joystick throttle boost (clamped to the per-gear caps) |
| `RC_DEADBAND` | 50 | How far RC sticks must move to register (μs) |
| `JOY_DEADBAND` | 480 | How far the joystick must move to register (ADC units, ~6% of travel) |

Smoothing is no longer an Arduino setting — it lives in the GL10 ESC's
Acceleration / Drag parameters (see `docs/GL10-PARAMETERS.md`).

After changing a value, re-upload the sketch to the Arduino using:

```bash
arduino-cli upload -p COM7 --fqbn arduino:renesas_uno:unor4wifi sketches/dual_track_control
```

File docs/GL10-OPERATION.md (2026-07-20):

# GL10 ESC — Operational Procedures

**Source:** XC-ESC GL10 official user manual (`docs/GL10-Manual.pdf`,
3-page image-based PDF from <https://www.xc-esc.com/product/rc-brushless-sensored-foc-gl10-esc-80a2-4s/>).

This document transcribes the manual's procedural sections (4, 5, 6, 8, 9)
so they live in the repo as text alongside the parameter reference in
`GL10-PARAMETERS.md`. The original PDF stays the authoritative source for
ambiguous wording — these are working notes, not a legal translation.

## Startup procedure (Manual §4)

Before applying throttle to a newly-powered ESC:

1. Inspect the wiring for shorts, opens, or loose connections.
2. Verify the motor turns freely by hand — nothing mechanically jammed.
3. Plug in the power cable.
4. Turn on the ESC switch.
5. Listen for the **"Normal Startup"** prompt tone (see §9 LED & beep
   reference). When that tone plays, startup is normal and throttle can be
   applied.

If you hear a fault tone instead of the startup tone, do **not** apply
throttle — consult the fault-warning rows in §9.

## Throttle range calibration (Manual §5)

This teaches the ESC the exact PWM pulse widths your signal source uses for
full-reverse, full-forward, and neutral. The procedure is per-ESC, not
per-pair — each ESC stores its own learned range.

**Three-step procedure with the stick (or Arduino signal):**

1. **ESC powered off, signal held at full reverse.** Power on the ESC.
   Wait until the red/green LED indicator goes off — that confirms the ESC
   has entered calibration mode and registered the reverse endpoint.
2. **Quickly move the signal to full forward.** Wait for the green LED to
   go off — forward endpoint stored.
3. **Quickly move the signal to neutral (center).** Wait for the red LED
   to go off — neutral endpoint stored.

**Success indication:** the ESC repeats a prompt four times — red and green
LEDs solid + motor "lo, ro, do" tone.

**Failure indication:** red/green LEDs stay off, no completion tone. Power
the ESC down and retry — common causes are moving between positions too
slowly, or the signal source not actually reaching the documented PWM
extremes.

### Arduino integration note

In this project the Arduino sits between the receiver and the ESCs, so
"stick at full reverse" means **Arduino emitting 1000 µs** on that ESC's
signal lead. Two options when running the procedure:

- **Option A (recommended):** drive the calibration from the Arduino so
  each ESC learns the *exact* µs range the firmware actually outputs (this
  project: 1000/1500/2000). Write a one-off sketch that holds 1000 µs at
  boot, then advances to 2000 µs and 1500 µs on Serial input or fixed delays.
  The production firmware deliberately contains **no** calibration
  passthrough (the temporary `CALIBRATION_MODE` flag was removed, #122) — a
  dedicated bench sketch under `sketches/` is the sanctioned home for this
  one-off, written when recalibration is actually needed.
- **Option B:** bypass the Arduino, plug the receiver throttle channel
  straight into the ESC's signal lead, and use the physical transmitter
  stick for the three positions. Faster if you don't mind the temporary
  re-wire — but the ESC ends up calibrated to the transmitter's range, not
  the Arduino's, and any small offset between the two reappears as a
  per-ESC asymmetry.

After calibration, power-cycle the ESC. Repeat on the second ESC.

## Bluetooth pairing & default password (Manual §6)

- **Bluetooth name format:** `<model>-<ESC-code-ID>`, e.g. `KC_010-1CB1`
  where `KC_010` is the product family and `1CB1` is this ESC's hex
  code-ID. Each ESC has a unique code-ID so two ESCs on the bench advertise
  distinct Bluetooth names.
- **Default password:** `1234`.

Use the XC-Link Bluetooth app to read/write parameters. The GL10 has no
programming card or DIP switches — Bluetooth is the only configuration
channel.

## Factory reset (Manual §8)

### Restore Bluetooth password / boot mode

If the Bluetooth password is lost (or you need to force the ESC into Boot
mode to upgrade firmware):

1. Short the ESC's BEC- pin to ground (red wire end of the BEC connector).
2. Turn on the ESC.
3. When the green LED goes off and the red LED comes on, disconnect the
   short.
4. Remove the shorting wire.

Result: Bluetooth name and password reset to factory defaults (password
`1234`). The same procedure activates Boot mode for firmware upgrade if a
hardware error has bricked the normal boot path.

### Restore parameter values

To restore the configurable parameters (the items in `GL10-PARAMETERS.md`)
to factory defaults: open the XC-Link app's parameter page and tap
**Default**. This does not touch the throttle range calibration — that's
stored separately and must be re-run via §5 if needed.

### What factory-reset does **not** clear

- **Throttle range calibration** (§5 procedure) — stays unless you re-run
  the calibration. This is exactly why two ESCs with identical exported
  parameter files can still produce asymmetric throttle readings: their
  learned endpoint ranges differ.
- **Per-unit Hall sensor / motor auto-detect results** (if the GL10 stores
  any — the manual doesn't explicitly document this, but FOC ESCs in this
  class typically do). If swapping in a new motor, expect to re-run any
  motor-pairing or Hall-alignment routine the XC-Link app offers.

## LED & beep reference (Manual §9)

This is a working extract of the prompt table. The manual's column layout
is dense and image-based; verify against `docs/GL10-Manual.pdf` page 3 for
any ambiguous case.

### Normal-operation prompts

| Condition | Light | Sound |
| --- | --- | --- |
| Throttle not zeroed at boot | Red flashing | Long tone "beep1" |
| Throttle zeroed at boot | Red flashing | Long tone "beep2" |
| Voltage normal (in range) | Red/green steady | Detected cell-count beeps |
| Voltage low (warning) | Red flashing | Long tone "beep3" |
| Voltage over-range | Red flashing | Long tone "beep4" |
| Temperature normal | (no indicator) | — |
| Temperature too high (MOS or motor) | Red rapid flash | Short tone repeated |
| Throttle calibration in progress | (varies by step — see §5) | — |
| Throttle calibration success | Red & green solid | "lo, ro, do" motor tone, repeated 4× |

### Brake / startup prompts

| Condition | Light | Sound |
| --- | --- | --- |
| Brake engaged | Red flash | — |
| Normal startup (initial boot tone) | Red & green | Battery cell-count + short confirmation |
| Normal startup (after throttle returns from non-zero) | Green steady | — |

### Fault prompts (ESC self-check abnormality)

When the ESC reports a fault during self-check, the type of fault is
encoded in the beep pattern (1×, 2×, 3×, 4×, or 5× repeats). See the
manual's "Fault warning" rows for the per-pattern meaning — patterns
include MOS over-temp, motor over-temp, over-current, Hall failure, and
under/over-voltage. Reset by power-cycling once the underlying condition
clears; persistent faults indicate hardware damage and require service.

## GL540L motor

We do not currently have a manufacturer manual for the GL540L motor in the
repo. The GL540L is a sensored brushless motor paired with the GL10 ESC;
configuration and tuning happens on the ESC side, not the motor. If a
motor-specific manual surfaces (e.g. Hall sensor pinout, magnetic
alignment procedure, recommended idle current), add it as
`docs/GL540L-Manual.pdf` and create a `GL540L-OPERATION.md` alongside this
file.

## See also

- `docs/GL10-Manual.pdf` — original 3-page manual
- `docs/GL10-PARAMETERS.md` — configurable parameters table + code-context
  analysis (what each parameter does to the Arduino's control commands)
- `docs/XBUS-PROTOCOL.md` — X.BUS protocol reference (the alternate
  digital control path for these ESCs, currently deferred)

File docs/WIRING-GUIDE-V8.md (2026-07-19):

# Wiring Guide V8.0 — UNO R4 WiFi + GL10 FOC

**Date:** 2026-05-24
**Board:** Arduino UNO R4 WiFi (Renesas RA4M1 + ESP32-S3)
**Shield:** Sensor Shield V5.0
**ESCs:** 2× GL10 80A Sensored Brushless FOC
**Motors:** 2× GL540L Sensored Brushless (1× CW, 1× CCW)

---

## 1. System Overview

```text
┌─────────────────────────────────────────────────────┐
│                    UNDER THE SEAT                    │
│                                                     │
│  ┌─────────────┐    ┌──────────┐                    │
│  │  Joystick   │───→│  Shield  │                    │
│  │  (A0, A1)   │    │  V5.0    │                    │
│  └─────────────┘    │  on UNO  │                    │
│                     │  R4 WiFi │                    │
│                     └────┬─────┘                    │
│                          │                          │
│                    9-PIN CABLE                      │
│                     (modular)                       │
│                          │                          │
├──────────────────────────┼──────────────────────────┤
│                    ON THE FRAME                      │
│                          │                          │
│                  ┌───────┴────────┐                  │
│                  │ Interface Board │                 │
│                  │  (soldered)     │                 │
│                  └──┬───┬───┬──┬──┘                  │
│                     │   │   │  │                     │
│              ┌──────┘   │   │  └──────┐              │
│              │          │   │         │              │
│         ┌────┴───┐  ┌──┴───┴──┐  ┌───┴────┐        │
│         │ESC Left│  │Receiver │  │ESC Right│        │
│         │ GL10   │  │  R7FG   │  │  GL10   │        │
│         └────┬───┘  └─────────┘  └───┬────┘        │
│              │                       │              │
│         ┌────┴───┐              ┌────┴───┐          │
│         │Motor L │              │Motor R │          │
│         │GL540L  │              │GL540L  │          │
│         └────────┘              └────────┘          │
└─────────────────────────────────────────────────────┘
```

---

## 2. Pin Assignments — UNO R4 WiFi

| Pin | Signal | Direction | UART | Connection |
|-----|---|---|---|---|
| **D0** | X.BUS RX | Bus → Arduino | Serial1 (SCI2) | Interface board J4 |
| **D1** | X.BUS TX | Arduino → Bus | Serial1 (SCI2) | Interface board J3 |
| **D9** | PWM Left | Arduino → ESC | — | ESC Left throttle |
| **D10** | PWM Right | Arduino → ESC | — | ESC Right throttle |
| **D12** | S.BUS RX | Board → Arduino | sbusUart (SCI0) | Interface board J6 |
| **D8** | Piezo beeper | Arduino → piezo | — | Active piezo: alarms + horn (V7.11) |
| **A0** | Joystick Y | Joystick → Arduino | — | Throttle axis (14-bit ADC) |
| **A1** | Joystick X | Joystick → Arduino | — | Steering axis (14-bit ADC) |
| **VIN** | Power in | ESC → Arduino | — | BEC 7.4V |
| **5V** | Power out | Arduino → Board | — | Interface board +5V rail |
| **GND** | Ground | Common | — | All devices |

### Available Pins

| Pin | Notes |
|-----|---|
| D2, D3, D4, D5, D6, D7 | Free digital I/O |
| D11 | SCI0 TX (reserved — paired with D12 S.BUS UART) |
| D13 | Free (LED_BUILTIN) |
| A2, A3 | Free analog inputs |
| A4, A5 | I2C SDA/SCL (also Qwiic connector — no SCI on UNO R4 WiFi) |

### UART Architecture

| Port | SCI Channel | Pins | Baud | Purpose |
|---|---|---|---|---|
| Serial | — | USB-C | 115200 | Debug / uploads |
| Serial1 | SCI2 | D0 (RX), D1 (TX) | 115200 | X.BUS telemetry (both ESCs) |
| sbusUart | SCI0 | D12 (RX), D11 (TX) | 100000 8E2 | S.BUS RC input |
| Serial2 | SCI? | Internal | — | **Reserved for WiFi ESP32-S3** |

**Key difference from Nano R4:** SCI0 is on D11/D12 (not A4/A5). Same
hardware peripheral, different pins. A4/A5 are I2C-only on the UNO R4 WiFi.

---

## 3. Power

```text
ESC Left BEC (7.4V) ──→ 9-pin cable pin 6 ──→ Arduino VIN
                                                    │
                                          Buck converter (ISL854102FRZ)
                                                    │
                                                  5V rail
                                                    │
                              ┌─────────────────────┼─────────────────┐
                              │                     │                 │
                     Shield servo headers    Joystick (A0, A1)    9-pin cable pin 8
                       (SEL jumper IN)                                │
                                                              Interface board +5V
                                                                      │
                                                    ┌─────────────────┼──────────┐
                                                    │                 │          │
                                              RC Receiver     X.BUS pull-up   S.BUS
                                              (via J5)        R1 (4.7kΩ)     inverter
                                                                              R4 (10kΩ)
```

| Source | Voltage | Destination | Current |
|---|---|---|---|
| ESC Left BEC | 7.4V | Arduino VIN | — |
| Arduino regulator | 5V | Shield rail, joystick, interface board | ~300mA total |
| ESC Right BEC | — | **Disconnected** (red wire cut) | — |

**BEC setting:** Set to **7.4V** in TXC-Link app (ESC Left only).
**USB coexist:** Safe. Schottky diodes prevent backfeed. Plug USB anytime.
**Shield SEL jumper:** Leave **IN** (default). Arduino 5V powers servo headers.

---

## 4. Nine-Pin Cable

Waterproof 9-pin connector between the interface board (on the frame)
and the Arduino (under the seat). One cable, one disconnect point.

### Cable Pin Map

| Cable Pin | Shield Pin | Wire Color | Direction | Purpose |
|---|---|---|---|---|
| 1 | **D9** | Blue (thick) | Arduino → ESC | PWM left track |
| 2 | **D10** | Yellow | Arduino → ESC | PWM right track |
| 3 | **D1** | Green (thin) | Arduino → bus | X.BUS telemetry TX |
| 4 | **D0** | Blue (thin) | Bus → Arduino | X.BUS telemetry RX |
| 5 | **D12** | Red (thin) | Board → Arduino | S.BUS inverted (SCI0 RX) |
| 6 | **VIN** | Yellow (thick) | ESC → Arduino | Power in 7.4V |
| 7 | **GND** | Green (thick) | Common | Ground |
| 8 | **5V** | White (thin) | Arduino → board | 5V back to interface board |
| 9 | — | — | — | Spare (not connected) |

### Interface Board Side — 6 Female Servo Connectors

All connectors are standard **3-pin servo** (Signal, VCC, GND) for
structural support and modularity. VCC pin is soldered to the board
pad for mechanical strength but not electrically connected on signal-only
connectors (J3, J4, J6, F1, F2, F5).

| Connector | Pin 1 (Signal) | Pin 2 (VCC) | Pin 3 (GND) | Receives Plug From |
|---|---|---|---|---|
| F1 — PWM L | Signal | N/C (structural) | GND | ESC Left throttle servo |
| F2 — PWM R | Signal | N/C (structural) | GND | ESC Right throttle servo |
| F3 — XBUS TX | Signal | N/C (structural) | GND | Interface board J3 |
| F4 — XBUS RX | Signal | N/C (structural) | GND | Interface board J4 |
| F5 — SBUS | Signal | N/C (structural) | GND | Interface board J6 |
| F6 — Power | VIN 7.4V (pin 1) | GND (pin 2) | 5V return (pin 3) | ESC BEC + Arduino 5V |

### Arduino Shield Side — 6 Servo Connectors

All connectors are standard **3-pin servo** plugging into shield headers.
Shield headers provide VCC from the 5V rail on the middle pin — this is
harmless on signal-only connectors (not connected on the cable side).

| Connector | Shield Header | Pin 1 (Signal) | Pin 2 (VCC) | Pin 3 (GND) |
|---|---|---|---|---|
| S1 — PWM L | D9 | Signal | (from shield, unused) | GND |
| S2 — PWM R | D10 | Signal | (from shield, unused) | GND |
| S3 — XBUS TX | D1 | Signal | (from shield, unused) | GND |
| S4 — XBUS RX | D0 | Signal | (from shield, unused) | GND |
| S5 — SBUS | D12 | Signal | (from shield, unused) | GND |
| S6 — Power | VIN/5V/GND | VIN 7.4V (pin 1) | GND (pin 2) | 5V return (pin 3) |

### Direct to Shield (not through cable)

| Connector | Shield Pin | Wires |
|---|---|---|
| Joystick Y | A0 header | Signal + 5V + GND |
| Joystick X | A1 header | Signal + 5V + GND |

---

## 5. Interface Board

Full build plan in `docs/INTERFACE-BOARD.md`. Summary:

| Component | Purpose |
|---|---|
| R1 (4.7kΩ) | X.BUS bus pull-up to 5V |
| R2 (1kΩ) | Arduino TX series resistor (contention protection) |
| R3 (10kΩ) | S.BUS NPN base resistor |
| R4 (10kΩ) | S.BUS NPN collector pull-up |
| Q1 (2N3904) | S.BUS signal inverter |
| J1–J6 | 3-pin servo headers (plug-and-play) |

**Receiver plugs into J5** on the interface board. Gets 5V + GND from the
board's +5V rail (fed by cable pin 8). S.BUS signal goes through the NPN
inverter (Q1) and exits via J6 into the cable.

---

## 6. ESC Configuration (TXC-Link App)

| Setting | ESC Left | ESC Right |
|---|---|---|
| BEC Voltage | **7.4V** | Any (red wire cut) |
| X.BUS Address | **0** | **1** |
| Motor Rotation | Per track | Per track |
| Max Reverse Force | 100% | 100% |
| Simulation Inertia | 1 | 1 |
| Drag Force | 30% | 30% |
| Max Brake Force | 60% | 60% |
| Cutoff Voltage | 3.2V/cell | 3.2V/cell |

Full parameter reference: `docs/GL10-QUICK-REFERENCE.md`

---

## 7. Wire Labels

| Label | Cable Pin | Wire Color | From → To |
|---|---|---|---|
| PWM-L | 1 | Blue (thick) | D9 → ESC Left throttle |
| PWM-R | 2 | Yellow | D10 → ESC Right throttle |
| XBUS-TX | 3 | Green (thin) | D1 → Interface board bus |
| XBUS-RX | 4 | Blue (thin) | Interface board bus → D0 |
| SBUS | 5 | Red (thin) | Interface board Q1 → D12 |
| VIN-7V4 | 6 | Yellow (thick) | ESC BEC → Arduino VIN |
| GND | 7 | Green (thick) | Common ground |
| 5V-OUT | 8 | White (thin) | Arduino 5V → Interface board |
| SPARE | 9 | — | — |
| JOY-Y | — | — | Joystick → A0 (direct to shield) |
| JOY-X | — | — | Joystick → A1 (direct to shield) |

---

## 8. Safety Checklist

- [ ] ESC Right BEC red wire is cut/insulated
- [ ] ESC Left BEC set to 7.4V in TXC-Link
- [ ] BEC power goes to VIN, not 5V pin
- [ ] Shield SEL jumper is IN (default)
- [ ] X.BUS addresses: ESC Left = 0, ESC Right = 1
- [ ] Both ESCs calibrated (Reverse → Forward → Neutral)
- [ ] All grounds connected (common ground bus)
- [ ] Interface board continuity checks pass
- [ ] USB cable disconnected during field operation (or fine to leave)

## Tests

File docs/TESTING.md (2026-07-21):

# Host Testing — Characterization + Safety Invariants (#47, #131 — Epic #116 Phase B)

The firmware's control logic runs on a laptop, byte-for-byte unchanged, inside
a fake Arduino environment. Two suites share the harness: **characterization**
(#47) locks in example behavior, and **invariants** (#131) asserts safety
properties that must always hold, under injected faults. Together they are the
**primary safety net for any structural change**: every PR must keep them
green, proving behavior parity while no hardware is available.

## How it works — zero firmware changes

The production sketch is not modified for testing. Each test binary compiles
`sketches/dual_track_control/dual_track_control.ino` directly, plus the extracted
`sketches/dual_track_control/src/**/*.cpp` domain sources the sketch delegates
to (extracted during Phase D, #117 — complete). Pure suites live at the path of the
layer they test — the tree MIRRORS `src/` (#195) — with no firmware, no
stubs, and no `src/infrastructure/` sources (those include hardware headers
and are compiled only into the stub-backed firmware suites, #172):

```text
tests/
├── Makefile                    one host binary per test file; `make run`
├── vendor/doctest/doctest.h    doctest 2.4.12 (vendored, third-party — lint-exempt)
├── stubs/                      fake Arduino environment (test control surface)
│   ├── Arduino.h               fake clock (millis/micros), scripted analogRead,
│   │                           GPIO capture, UART/Serial stubs, map/constrain
│   ├── Servo.h                 captures attach/detach + every writeMicroseconds
│   ├── WiFiS3.h                inert AP/server/client + modem stub
│   ├── WDT.h                   counts refresh() calls
│   ├── sbus.h                  scripted S.BUS frames (bfs::SbusRx/SbusData)
│   └── SerialPortStub.h        Serial/Serial1/UART fakes — scripted RX, captured TX
├── characterization/           cross-cutting: compiles the REAL firmware
│   ├── FirmwareUnderTest.h     includes dual_track_control.ino + state reset
│   └── test_*.cpp              one focused suite per behavior area
├── invariants/                 cross-cutting: safety properties under faults
│   ├── InvariantChecks.h       reusable checkers + loop driver (#131)
│   └── test_invariant_*.cpp    one property suite per safety invariant
├── domain/                     mirrors src/domain/ (#195)
│   ├── battery/                test_voltage_plausibility,
│   │                           test_battery_ladder_domain
│   ├── thermal/                test_thermal_domain
│   ├── operator_input/         test_operator_input_domain
│   ├── drive/                  test_curvature_drive_domain,
│   │                           test_gear_mixer_domain
│   └── safety/                 test_safety_supervisor_domain,
│                               test_output_gate_domain
├── telemetry/                  mirrors src/telemetry/: test_telemetry_scaling,
│                               test_observer_encoders
└── alerts/                     mirrors src/alerts/: test_alert_policy_domain
```

The stub headers shadow the real Arduino/library headers via include order
(`-I tests/stubs` first), so `#include <Arduino.h>` inside the sketch resolves
to the fake. Each stub owns its scripting state and reset (all under
`namespace stub`); `resetHarness()` in `FirmwareUnderTest.h` resets every stub
plus the firmware globals. Tests then script inputs (S.BUS frames, ADC values,
telemetry voltages, the clock) and assert on captured outputs (servo
microseconds, pin states, alarm patterns).

Because tests live in the same translation unit as the firmware, they can read
every internal (including `const` globals) — that is deliberate: this is a
characterization harness, not an API. `resetFirmwareState()` in
`FirmwareUnderTest.h` restores all mutable firmware globals between test
cases; it must be updated when a global is added (the harness fails loudly in
review otherwise — see the PR checklist in the workflow rules).

## What is characterized (V7.34 baseline, captured 2026-07-05)

| Suite | Behavior locked in |
| --- | --- |
| `test_curvature_drive` | straight-line, pure pivot (per-gear caps), smoothstep blend band, pivot throttle taper (#114), reverse steering sign (#86), outer-track ceiling + desaturation (#96), gear average cap (#72) |
| `test_input_shaping` | `sbusToServo` endpoints/center, RC + joystick deadbands, expo curves, `rcCommand` gains + reverse clamp, `updateJoystick` ADC→command pipeline (#90) |
| `test_gear_and_caps` | CH4 gear thresholds, S.BUS-invalid → Eco failsafe, Eco/thermal gear locks, `reverseCap()` per gear (#113), `outCapToX`, per-gear joystick forward caps |
| `test_mixer` | `maxOppose` algebra, override Mode 1/2/3 selection (#90) |
| `test_battery_ladder` | plausibility gating, worst-of-two, Eco-lock 10.8 V/15 s, cutoff 10.0 V/1.5 s latch + alarm assertion, boot gate + fail-open (#65) |
| `test_thermal_stages` | 80/90/95 °C stages, hysteresis releases, 1 s trip debounce, telemetry-dropout hold, restored flourish (#111) |
| `test_output_gate` | ACTIVE→HOLD ease-out ramp→CUT detach, RC-loss auto-recovery, cutoff latch (#88) |
| `test_alerts` | horn OR-ing, one-shot patterns, alarm priority ladder, inactivity 60 s, low-V debounce/latch + startup grace (#51/#68) |
| `test_telemetry_parse` | X.BUS checksum, 0x10 response parsing, register scaling, EMA weights, per-ESC staleness watchdog |
| `test_control_loop` | end-to-end `setup()`+`loop()`: scripted S.BUS → servo µs, failsafe to neutral, exactly one `WDT.refresh()` per pass |

Characterization tests capture **current behavior** — including behavior that
might look odd. If a test fails after a refactor, the refactor changed
behavior; fix the code, not the test. Changing an expected value requires an
issue + operator sign-off (it is a behavior change, not a refactor).

## Safety invariants + fault injection (#131)

`tests/invariants/` asserts **properties**, not examples: things that must hold
for any input combination, under injected faults. The invariant list — verbatim
from issue #131, with constants and per-file links — lives in
[`docs/SAFETY.md`](SAFETY.md); the motivating incident is #69 (blocking Wi-Fi
send froze `loop()` while the ESCs held the last PWM).

| Suite | Property held |
| --- | --- |
| `test_invariant_output_bounds` | outputs within [1000, 2000] µs for any input, incl. NaN/Inf/out-of-range |
| `test_invariant_stale_rc_neutral` | stale/failsafe RC ⇒ neutral in every override mode, joystick live or not |
| `test_invariant_cutoff_dominates` | battery-cutoff latch ⇒ neutral within 500 ms then silence, forever; boot-with-low-pack never drives |
| `test_invariant_thermal_monotone` | rising thermal stage never increases propulsion authority; dropout holds state |
| `test_invariant_plausibility` | implausible/stale/spiking telemetry never trips or releases the ladders |
| `test_invariant_gear_reverse_caps` | average track speed never exceeds the active gear/reverse cap |

Mechanics: `InvariantChecks.h` provides `runControlPasses()`, which drives the
real `loop()` at flight cadence and re-checks the universal invariants
(`checkInvariantsNow()`) after **every** pass — each scenario is a continuous
property check, not an endpoint assertion. Same rule as characterization:
weakening an invariant expectation is a behavior change → own issue + operator
sign-off.

## Running

```sh
make -C tests run          # Linux/WSL/CI: build + run every suite
make -C tests               # build only
```

On this project's Windows dev machine the suite runs through WSL:
`wsl -e make -C tests run`. CI runs it on every push/PR via
`.github/workflows/unit-tests.yml` (required status check).

## Commit gate (hard block)

Three layers, per issue #47:

1. **`.githooks/pre-commit`** — native git hook, the primary gate for EVERY
   commit (agent or human): runs the suite whenever firmware/tests/workflow
   files are staged, plus the firmware-without-tests guard below. Activate
   once per clone: `git config core.hooksPath .githooks`.
   Emergency human bypass: `git commit --no-verify` (document why in the PR).
2. **`.claude/hooks/test-gate.py`** — Claude Code `PreToolUse[Bash]` hook
   that makes layer 1 agent-proof: it refuses `--no-verify`/`-n` on real
   `git commit` invocations and blocks commits in a clone where
   `core.hooksPath` was never activated. It parses the command (JSON +
   `shlex`, #206) so benign flags in compound commands (`grep -n`) or prose
   inside quoted bodies never false-positive; `git -C <path> commit` is
   still caught. Wired in `.claude/settings.json` (#193):

   ```json
   "PreToolUse": [
     {
       "matcher": "Bash",
       "hooks": [
         { "type": "command", "command": "python3 \"$CLAUDE_PROJECT_DIR/.claude/hooks/test-gate.py\"", "timeout": 30000 }
       ]
     }
   ]
   ```

   Registration itself is CI-checked: `scripts/check_hook_registration.py`
   (run by `hooks-selftest.yml`) fails when a script in `.claude/hooks/` is
   not referenced by any registered hook, and functionally exercises the
   gate across every spelling (the checker's case list is the canonical
   inventory): bypass flags blocked in exact, bundled (`-anm`), abbreviated
   (`--no-verif`), glued-separator, wrapper/environment-prefixed,
   multi-line, line-continuation, redirection-interleaved, nested-shell
   (`sh -c`), and `git -C`/`--git-dir=` forms — failing CLOSED on
   malformed or adversarially deep input; inactive `core.hooksPath`
   blocked in the repo the commit TARGETS; benign flags, quoted prose,
   short-option values, post-`--` pathspecs, heredoc commit messages, and
   `git` as another command's data all pass.

3. **CI `unit-tests` job** — the layer that cannot be bypassed; required for
   merge.

The firmware-without-tests guard blocks a commit that stages changes under
`sketches/dual_track_control/` without staging any change under `tests/`. If the
firmware change genuinely needs no test update (comment-only, debug text),
re-run as `DIGGER_NO_TEST_CHANGE=1 git commit ...` and say why in the PR.

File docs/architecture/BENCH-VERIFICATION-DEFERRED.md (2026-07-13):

# Deferred Bench Verification — epic #116 refactor

No hardware is available during the architecture remediation (constraint locked
2026-07-05), so refactor PRs are verified by compile + host tests + review
only. **Every PR that would normally get a bench check appends its physical
checks here.** When the machine is available again, run this entire checklist
in one session, then log the flash in `docs/FIRMWARE-UPLOAD-LOG.md` as usual.

> Rule: an item is only removed once it has been physically verified and the
> result noted. If any item fails, the refactor PR that added it is the first
> suspect.

## Standing checks (run regardless of which PRs merged)

- [ ] Stick→track response identical to V7.34 baseline in all 3 gears, forward/reverse/pivot (feel + serial CSV compare)
- [ ] RC-loss failsafe: ease to neutral, then no pulses; ESCs beep; recovery on signal return
- [ ] Battery ladder on bench supply: Eco-lock ~10.8 V (15 s), alarm 10.5 V, cutoff 10.0 V latched
- [ ] Thermal stages (heat gun / simulated): trill ≥80 °C, Eco ≥90 °C, cut ≥95 °C, auto-recovery + restored flourish; confirm 95 °C sits just BELOW the GL10's own (unpublished) internal thermal limit so our warned cut fires first (src/config/ThermalConfig.h note)
- [ ] Wi-Fi dashboard: connects, SSE at ~5 Hz, page load doesn't perturb control (watchdog silent)
- [ ] Horn, Wi-Fi-ready beep, inactivity alarm patterns unchanged
- [ ] Loop rate still ~20 kHz idle (serial banner / measurement)

## Per-PR additions

Append rows below as PRs merge.

| Date | PR | What to verify physically |
| --- | --- | --- |

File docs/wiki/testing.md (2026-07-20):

---
sources:
  - docs/TESTING.md
  - tests/
---

# Testing

Host-side suites that compile the **real firmware** (`dual_track_control.ino`) against
stub Arduino headers — no hardware needed. Canonical guide, commands, and the
commit gate: [TESTING](../TESTING.md).

- **Characterization suite** (`tests/characterization/`) — locks current
  behavior; the parity gate for every firmware-touching PR
- **Invariant suite** (`tests/invariants/`) — property tests + fault
  injection for the [safety system](safety-system.md); each maps to a row in
  [SAFETY](../SAFETY.md)
- **Commit gate** — `.githooks/pre-commit` blocks red suites and firmware
  changes without test changes
- **CI** — the same suites run in the `unit-tests` workflow alongside
  compile, lint, static-analysis, and structure checks; the
  `architecture-fitness` workflow additionally enforces the
  [target architecture's](architecture-remediation.md) dependency, file-size,
  and naming rules with a self-testing checker

**Test expectations are behavior law**: changing an expected value is a
behavior change requiring its own issue and operator sign-off — the core of
the [governance covenant](agent-governance.md). What cannot be tested on the
host (physical behavior) is deferred to a bench pass:
[BENCH-VERIFICATION-DEFERRED](../architecture/BENCH-VERIFICATION-DEFERRED.md).
Dashboard UI has its own local test path (Playwright screenshots) per
[.claude/rules/dashboard](../../.claude/rules/dashboard.md).

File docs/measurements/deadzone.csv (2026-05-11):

t_ms | joyY | joyX | tgtL | actL | thrL | ageL | tgtR | actR | thrR | ageR
3653 | 0 | 0 | 0 | 0 | 0 | 9999 | 0 | 0 | 0 | 9999
3663 | 0 | 0 | 0 | 0 | 0 | 9999 | 0 | 0 | 0 | 9999
3673 | 0 | 0 | 0 | 0 | 0 | 9999 | 0 | 0 | 0 | 9999
3683 | 0 | 0 | 0 | 0 | 0 | 9999 | 0 | 0 | 0 | 9999
3693 | 0 | 0 | 0 | 0 | 0 | 9999 | 0 | 0 | 0 | 9999
3703 | 0 | 0 | 0 | 0 | 0 | 9999 | 0 | 0 | 0 | 9999
3713 | 0 | 0 | 0 | 0 | 0 | 9999 | 0 | 0 | 0 | 9999
3723 | 0 | 0 | 0 | 0 | 0 | 9999 | 0 | 0 | 0 | 9999
3733 | 0 | 0 | 0 | 0 | 0 | 9999 | 0 | 0 | 0 | 9999
3743 | 0 | 0 | 0 | 0 | 0 | 9999 | 0 | 0 | 0 | 9999
3753 | 0 | 0 | 0 | 0 | 0 | 9999 | 0 | 0 | 0 | 9999
3763 | 0 | 0 | 0 | 0 | 0 | 9999 | 0 | 0 | 0 | 9999
3773 | 0 | 0 | 0 | 0 | 0 | 9999 | 0 | 0 | 0 | 9999
3783 | 0 | 0 | 0 | 0 | 0 | 9999 | 0 | 0 | 0 | 9999
3793 | 0 | 0 | 0 | 0 | 0 | 9999 | 0 | 0 | 0 | 9999
3803 | 0 | 0 | 0 | 0 | 0 | 9999 | 0 | 0 | 0 | 0
3813 | 0 | 0 | 0 | 0 | 0 | 0 | 0 | 0 | 0 | 10
3823 | 0 | 0 | 0 | 0 | 0 | 9 | 0 | 0 | 0 | 0
3833 | 0 | 0 | 0 | 0 | 0 | 20 | 0 | 0 | 0 | 10
3843 | 0 | 0 | 0 | 0 | 0 | 30 | 0 | 0 | 0 | 20
3853 | 0 | 0 | 0 | 0 | 0 | 40 | 0 | 0 | 0 | 30
3863 | 0 | 0 | 0 | 0 | 0 | 50 | 0 | 0 | 0 | 40
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

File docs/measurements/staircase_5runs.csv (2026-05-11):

t_ms | joyY | joyX | tgtL | actL | thrL | ageL | tgtR | actR | thrR | ageR
7890 | 0 | 0 | 0 | 0 | 0 | 0 | 0 | 0 | 0 | 9
7900 | 0 | 0 | 0 | 0 | 0 | 10 | 0 | 0 | 0 | 0
7910 | 0 | 0 | 0 | 0 | 0 | 0 | 0 | 0 | 0 | 9
7920 | 0 | 0 | 0 | 0 | 0 | 10 | 0 | 0 | 0 | 0
7930 | 0 | 0 | 0 | 0 | 0 | 0 | 0 | 0 | 0 | 9
7940 | 0 | 0 | 0 | 0 | 0 | 9 | 0 | 0 | 0 | 0
7950 | 0 | 0 | 0 | 0 | 0 | 0 | 0 | 0 | 0 | 10
7960 | 0 | 0 | 0 | 0 | 0 | 9 | 0 | 0 | 0 | 0
7970 | 0 | 0 | 0 | 0 | 0 | 0 | 0 | 0 | 0 | 10
7980 | 0 | 0 | 0 | 0 | 0 | 9 | 0 | 0 | 0 | 0
7990 | 0 | 0 | 0 | 0 | 0 | 0 | 0 | 0 | 0 | 10
8000 | 0 | 0 | 0 | 0 | 0 | 9 | 0 | 0 | 0 | 0
8010 | 0 | 0 | 0 | 0 | 0 | 0 | 0 | 0 | 0 | 10
8020 | 0 | 0 | 0 | 0 | 0 | 9 | 0 | 0 | 0 | 0
8030 | 0 | 0 | 0 | 0 | 0 | 0 | 0 | 0 | 0 | 10
8040 | 0 | 0 | 0 | 0 | 0 | 9 | 0 | 0 | 0 | 0
8050 | 0 | 0 | 0 | 0 | 0 | 0 | 0 | 0 | 0 | 10
8060 | 0 | 0 | 0 | 0 | 0 | 9 | 0 | 0 | 0 | 0
8070 | 0 | 0 | 0 | 0 | 0 | 0 | 0 | 0 | 0 | 10
8080 | 0 | 0 | 0 | 0 | 0 | 9 | 0 | 0 | 0 | 0
8090 | 0 | 0 | 0 | 0 | 0 | 0 | 0 | 0 | 0 | 10
8100 | 0 | 0 | 0 | 0 | 0 | 9 | 0 | 0 | 0 | 0
8110 | 0 | 0 | 0 | 0 | 0 | 0 | 0 | 0 | 0 | 9
8120 | 0 | 0 | 0 | 0 | 0 | 10 | 0 | 0 | 0 | 0
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

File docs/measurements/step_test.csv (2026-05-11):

t_ms | joyY | joyX | tgtL | actL | thrL | ageL | tgtR | actR | thrR | ageR
8370 | 0 | 0 | 0 | 0 | 0 | 0 | 0 | 0 | 0 | 9
8380 | 0 | 0 | 0 | 0 | 0 | 10 | 0 | 0 | 0 | 0
8390 | 0 | 0 | 0 | 0 | 0 | 0 | 0 | 0 | 0 | 9
8400 | 0 | 0 | 0 | 0 | 0 | 10 | 0 | 0 | 0 | 0
8410 | 0 | 0 | 0 | 0 | 0 | 0 | 0 | 0 | 0 | 9
8420 | 0 | 0 | 0 | 0 | 0 | 10 | 0 | 0 | 0 | 0
8430 | 0 | 0 | 0 | 0 | 0 | 0 | 0 | 0 | 0 | 9
8440 | 0 | 0 | 0 | 0 | 0 | 10 | 0 | 0 | 0 | 0
8450 | 0 | 0 | 0 | 0 | 0 | 0 | 0 | 0 | 0 | 9
8460 | 0 | 0 | 0 | 0 | 0 | 10 | 0 | 0 | 0 | 0
8470 | 0 | 0 | 0 | 0 | 0 | 0 | 0 | 0 | 0 | 9
8480 | 0 | 0 | 0 | 0 | 0 | 10 | 0 | 0 | 0 | 0
8490 | 0 | 0 | 0 | 0 | 0 | 0 | 0 | 0 | 0 | 9
8500 | 0 | 0 | 0 | 0 | 0 | 9 | 0 | 0 | 0 | 0
8510 | 0 | 0 | 0 | 0 | 0 | 0 | 0 | 0 | 0 | 10
8520 | 0 | 0 | 0 | 0 | 0 | 9 | 0 | 0 | 0 | 0
8530 | 0 | 0 | 0 | 0 | 0 | 0 | 0 | 0 | 0 | 10
8540 | 0 | 0 | 0 | 0 | 0 | 9 | 0 | 0 | 0 | 0
8550 | 0 | 0 | 0 | 0 | 0 | 0 | 0 | 0 | 0 | 10
8560 | 0 | 0 | 0 | 0 | 0 | 9 | 0 | 0 | 0 | 0
8570 | 0 | 0 | 0 | 0 | 0 | 0 | 0 | 0 | 0 | 9
8580 | 0 | 0 | 0 | 0 | 0 | 10 | 0 | 0 | 0 | 0
8590 | 0 | 0 | 0 | 0 | 0 | 0 | 0 | 0 | 0 | 9
8600 | 0 | 0 | 0 | 0 | 0 | 10 | 0 | 0 | 0 | 0
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

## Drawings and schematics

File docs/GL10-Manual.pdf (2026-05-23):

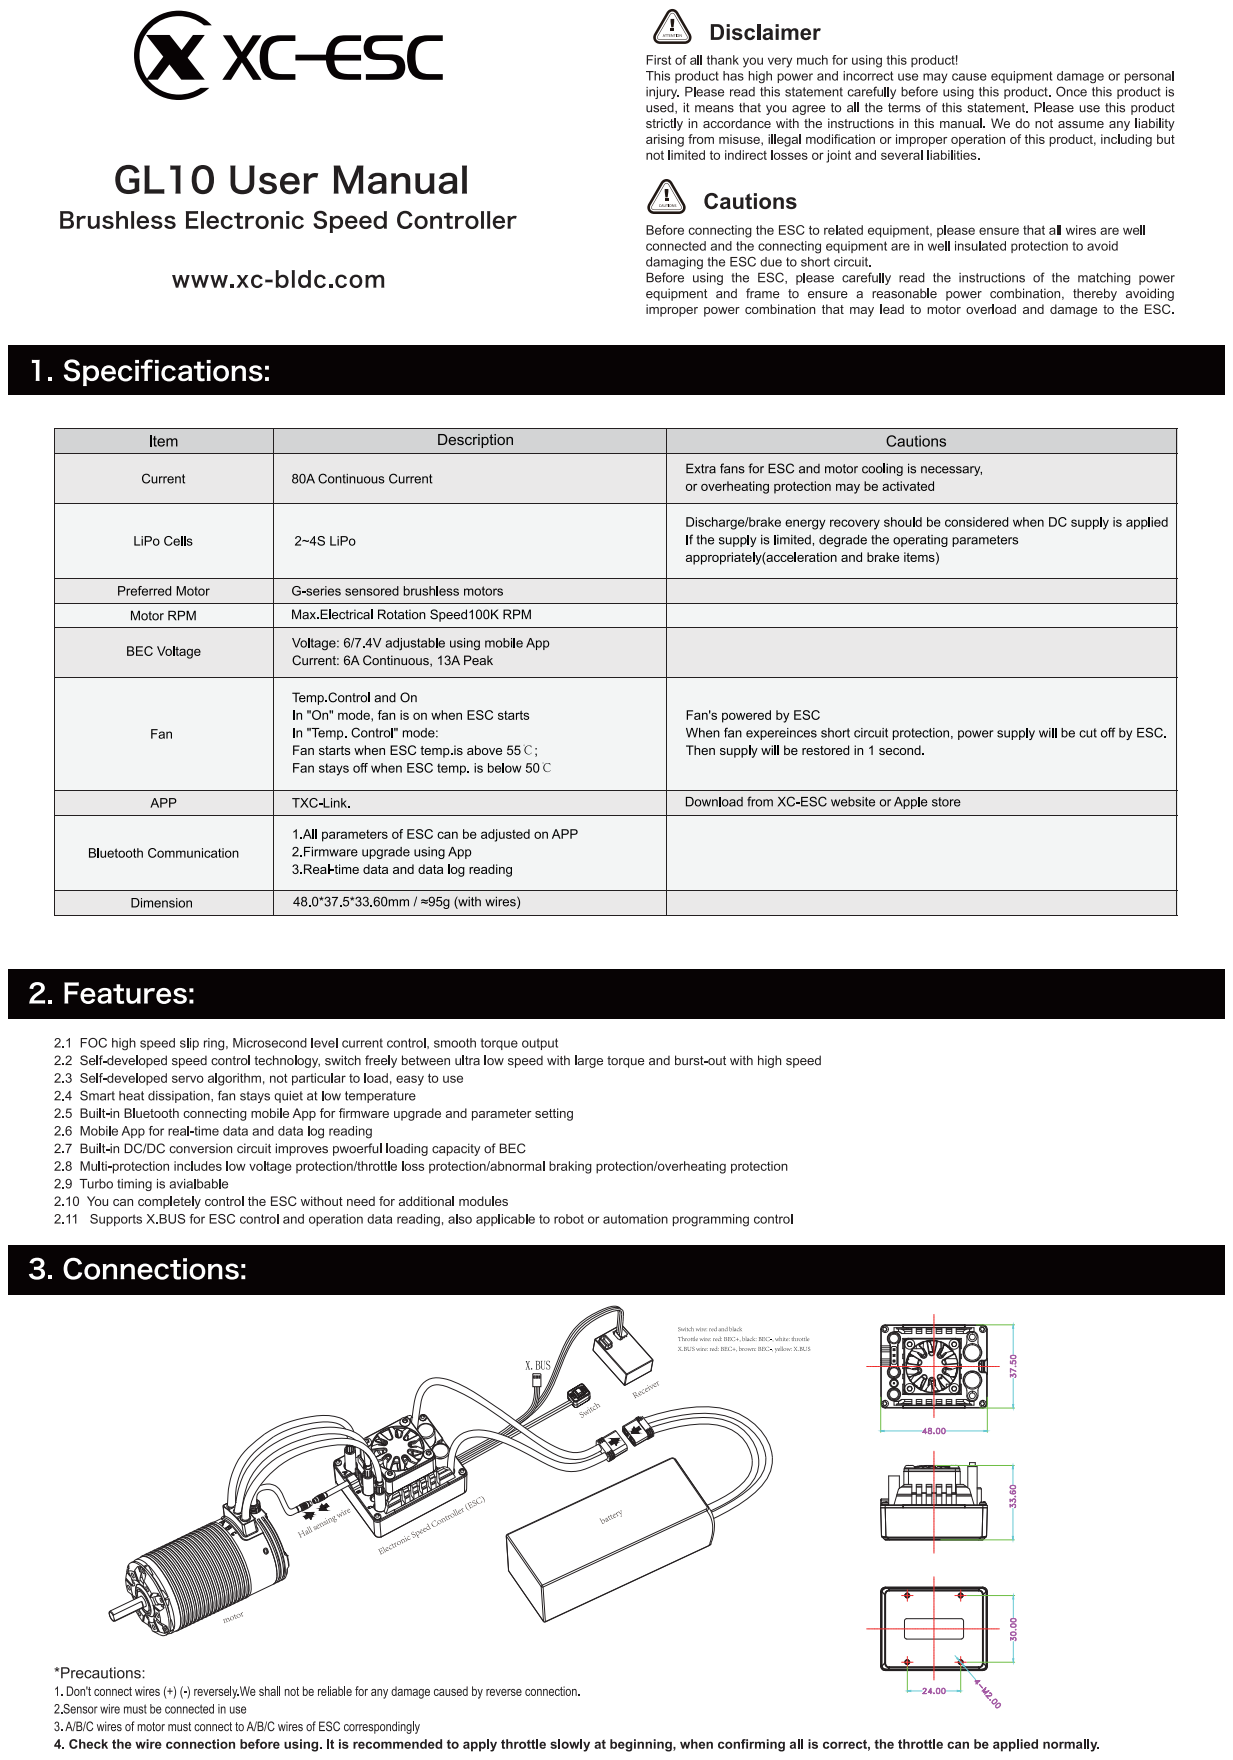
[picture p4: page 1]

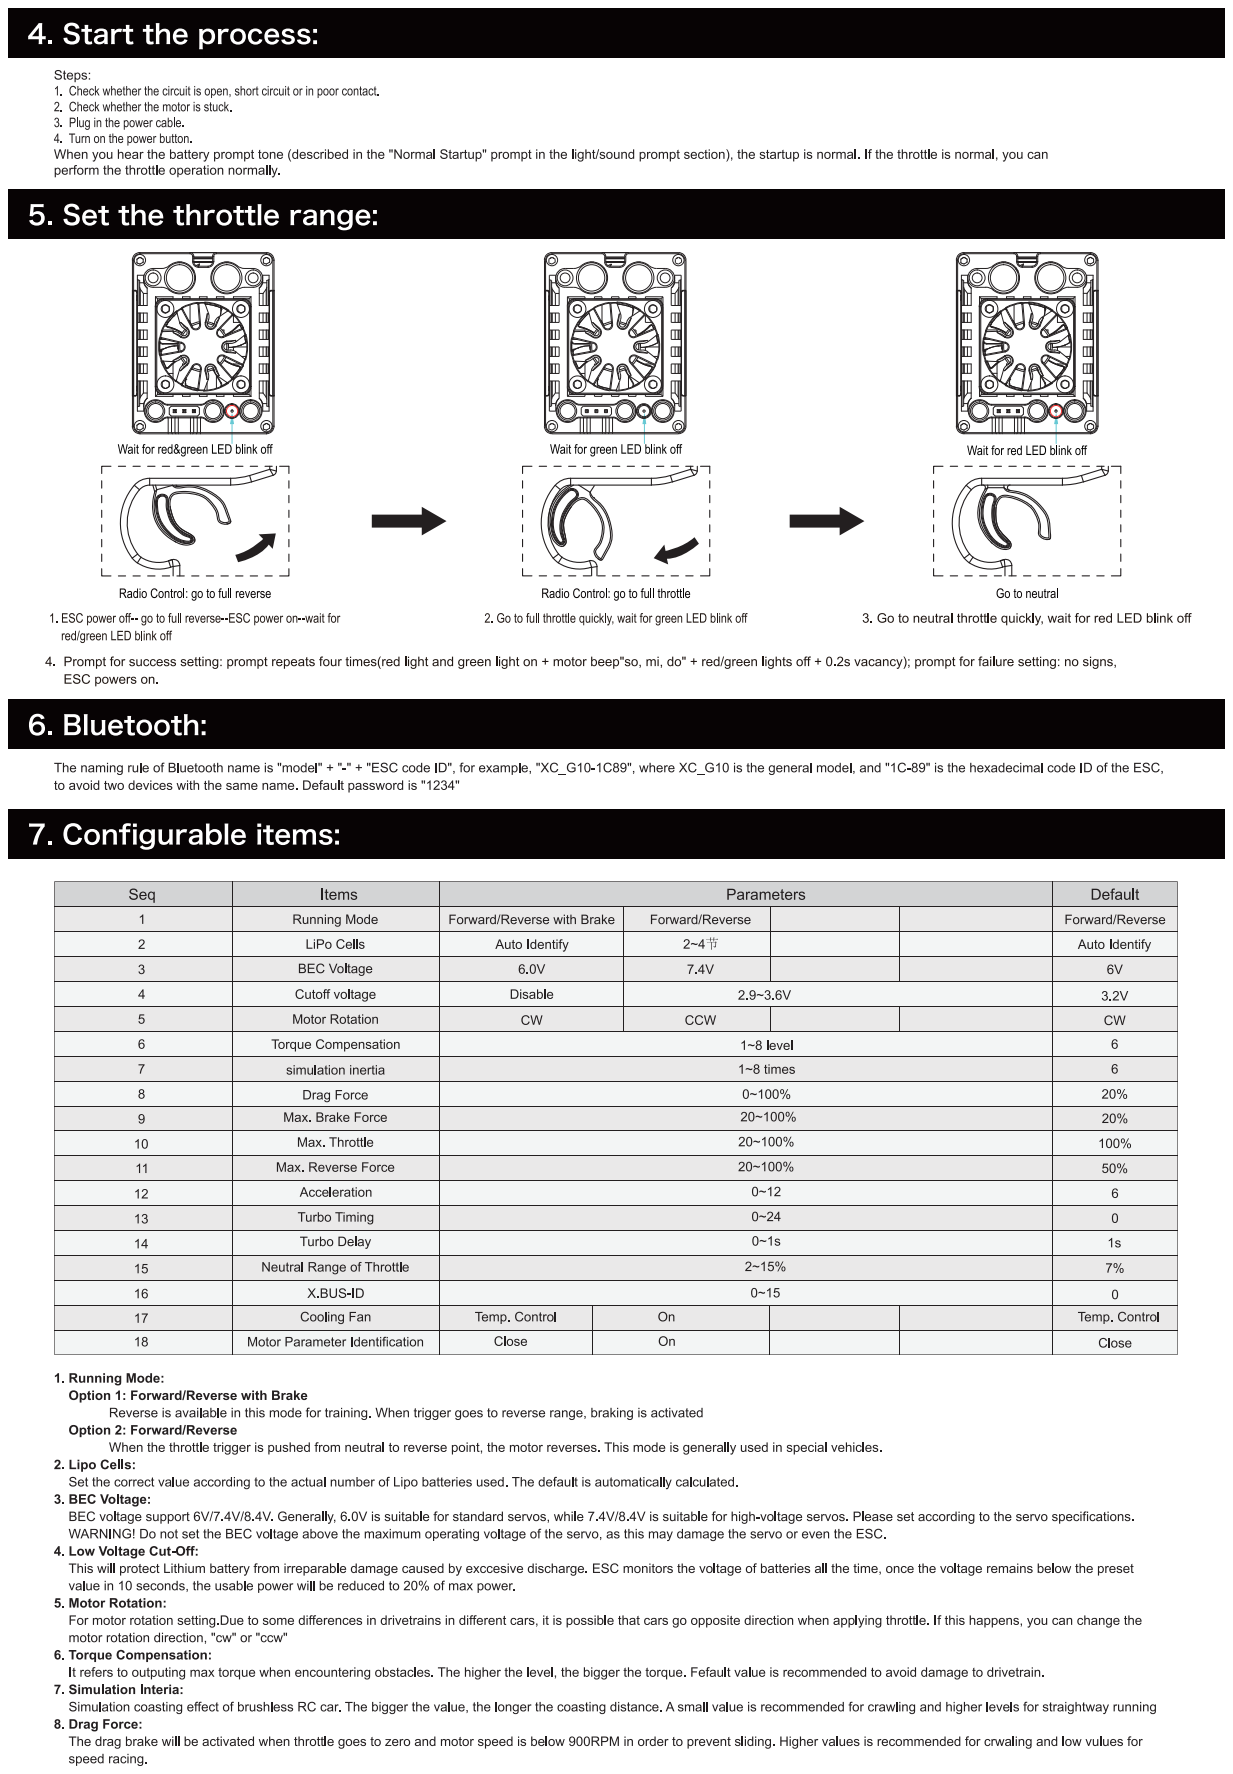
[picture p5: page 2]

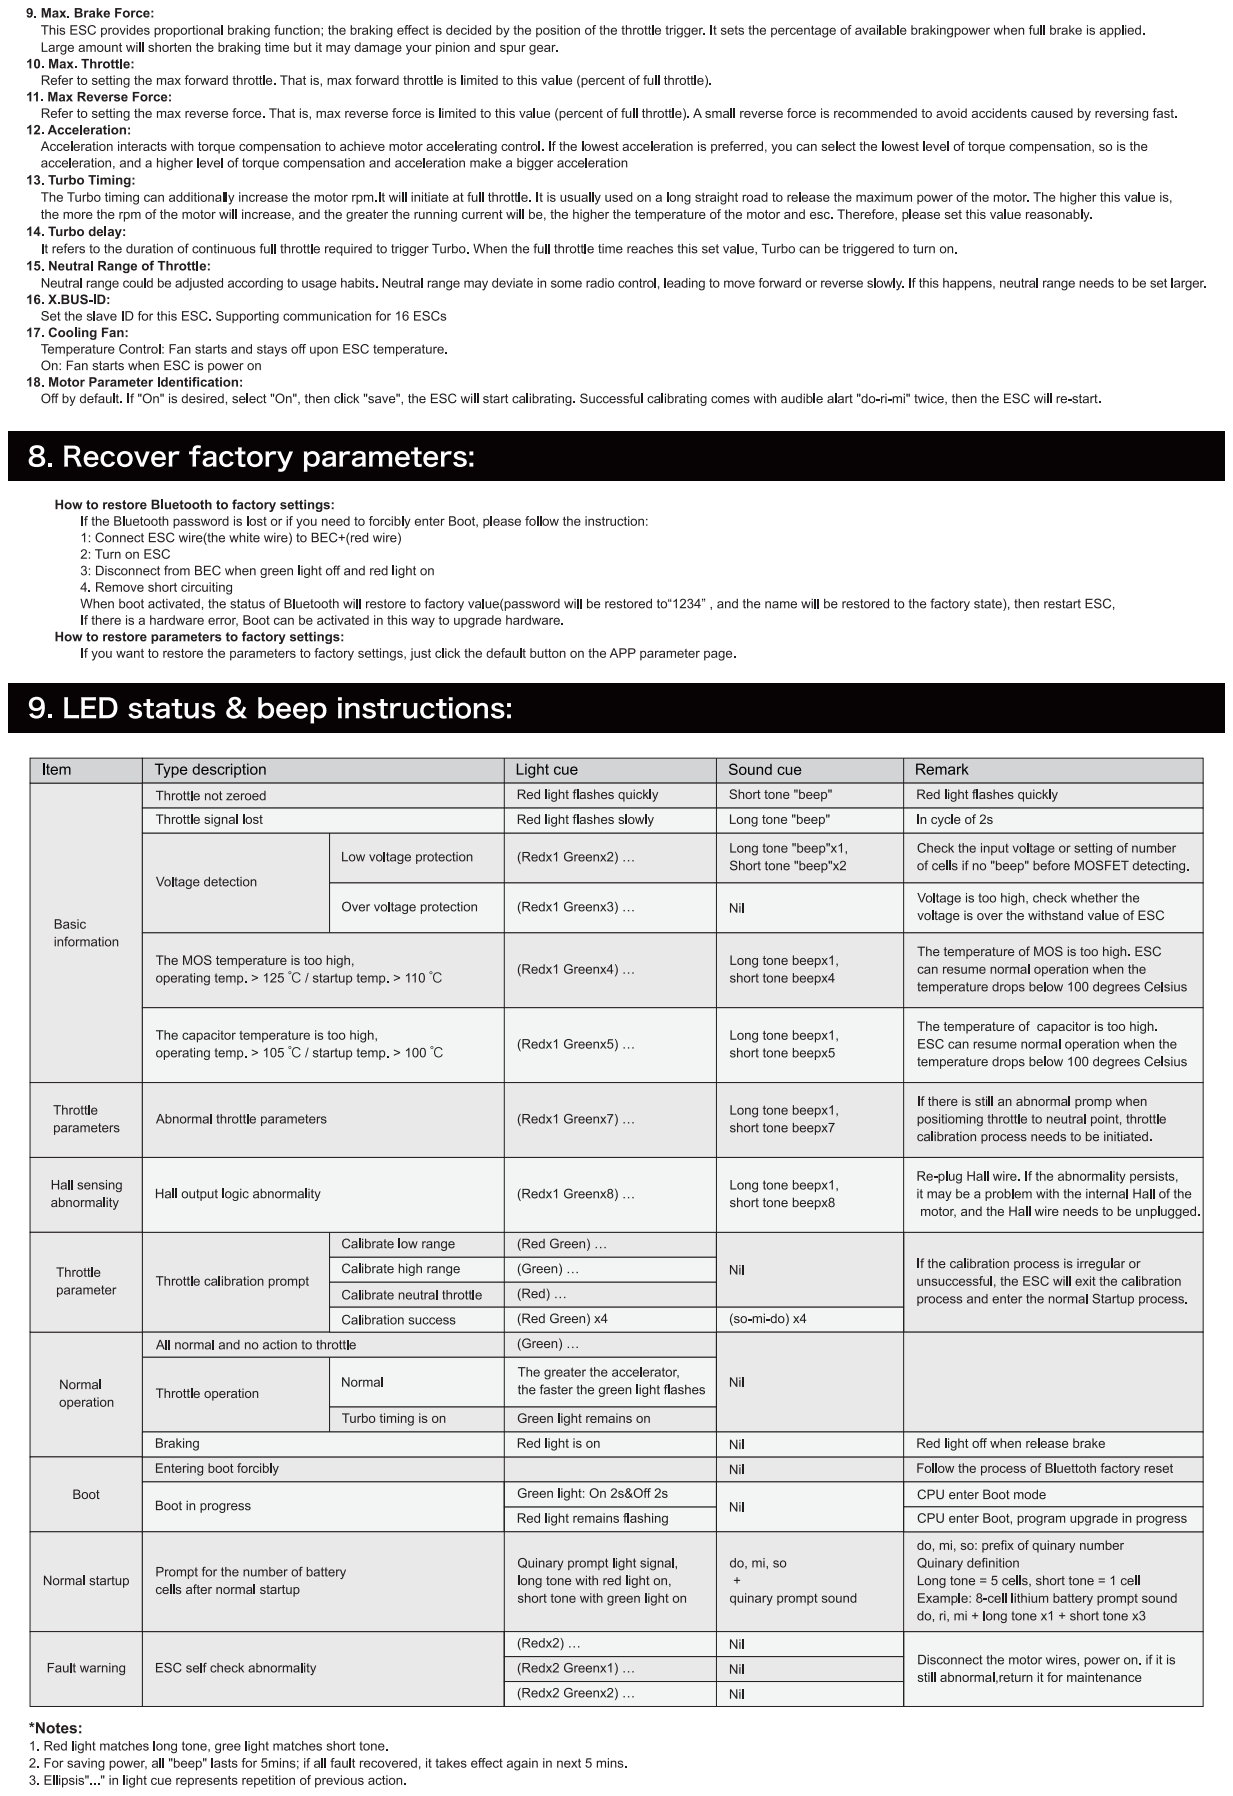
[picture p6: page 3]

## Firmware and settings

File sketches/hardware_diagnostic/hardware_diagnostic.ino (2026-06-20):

// ============================================================
// Hardware Diagnostic Sketch — Arduino UNO R4 WiFi
// Version: 2.1 (2026-03-31)
//
// Uses pulseIn() for RC channels (not interrupts — D4 and D7
// don't support attachInterrupt on UNO R4 WiFi Renesas core).
//
// CSV format (~10 Hz):
//   RC1,RC2,RC4,RC5,JoyY,JoyX,OutL,OutR,XbusB
//
// Pin assignments:
//   D2  <- RC CH1 (Left motor)       [pulseIn]
//   D4  <- RC CH2 (Right motor)      [pulseIn]
//   D3  <- RC CH4 (Control mode)     [pulseIn]
//   D7  <- RC CH5 (Override switch)  [pulseIn]
//   A0  <- Joystick Y (Throttle)
//   A1  <- Joystick X (Steering)
//   D9  -> Left ESC  (Servo PWM, held neutral)
//   D10 -> Right ESC (Servo PWM, held neutral)
// ============================================================

#include <Servo.h>

// ---- Pin Definitions ----
const int PIN_RC_CH1 = 2;   // Left motor (pre-mixed by TX)
const int PIN_RC_CH4 = 3;   // Control mode selector
const int PIN_RC_CH2 = 4;   // Right motor (pre-mixed by TX)
const int PIN_RC_CH5 = 7;   // Override switch
const int PIN_JOY_Y  = A0;  // Joystick throttle
const int PIN_JOY_X  = A1;  // Joystick steering
const int PIN_ESC_L  = 9;   // Left ESC servo output
const int PIN_ESC_R  = 10;  // Right ESC servo output

// ---- ESC Outputs ----
Servo escLeft, escRight;

// ---- Timing ----
uint32_t lastSummary = 0;
const uint32_t SUMMARY_INTERVAL = 10000;
uint32_t startTime = 0;

// ---- Voltage Tracking ----
int joyYMin = 16383, joyYMax = 0;
int joyXMin = 16383, joyXMax = 0;

// ---- RC pulse timeout (25ms = slightly more than one 50Hz frame) ----
const uint32_t PULSE_TIMEOUT = 25000;  // microseconds

void setup() {
  Serial.begin(115200);
  while (!Serial && millis() < 3000) {}
  delay(500);

  Serial.println("# ==========================================");
  Serial.println("# HARDWARE DIAGNOSTIC v2.1 — Arduino UNO R4 WiFi");
  Serial.println("# RC read via pulseIn (no interrupts)");
  Serial.println("# ==========================================");

  // 14-bit ADC
  analogReadResolution(14);

  // RC inputs
  pinMode(PIN_RC_CH1, INPUT);
  pinMode(PIN_RC_CH2, INPUT);
  pinMode(PIN_RC_CH4, INPUT);
  pinMode(PIN_RC_CH5, INPUT);

  // ESC outputs — hold neutral
  escLeft.attach(PIN_ESC_L);
  escRight.attach(PIN_ESC_R);
  escLeft.writeMicroseconds(1500);
  escRight.writeMicroseconds(1500);

  Serial.println("# Format: RC1,RC2,RC4,RC5,JoyY,JoyX,OutL,OutR,XbusB");
  Serial.println("# RC CH1[D2], CH2[D4], CH4[D3], CH5[D7]");
  Serial.println("# Joy Y[A0], Joy X[A1], ESC L[D9], ESC R[D10]");
  Serial.println("# ");

  startTime = millis();
}

void loop() {
  // ---- Read RC channels via pulseIn ----
  uint32_t pw1 = pulseIn(PIN_RC_CH1, HIGH, PULSE_TIMEOUT);
  uint32_t pw2 = pulseIn(PIN_RC_CH2, HIGH, PULSE_TIMEOUT);
  uint32_t pw4 = pulseIn(PIN_RC_CH4, HIGH, PULSE_TIMEOUT);
  uint32_t pw5 = pulseIn(PIN_RC_CH5, HIGH, PULSE_TIMEOUT);

  // ---- Read joystick (double-read to avoid ADC channel crosstalk) ----
  // First read after channel switch picks up residual charge from previous channel.
  // Discard it and read again for a clean sample.
  analogRead(PIN_JOY_Y); delayMicroseconds(100);
  int jy = analogRead(PIN_JOY_Y);
  analogRead(PIN_JOY_X); delayMicroseconds(100);
  int jx = analogRead(PIN_JOY_X);

  // Track min/max
  if (jy < joyYMin) joyYMin = jy;
  if (jy > joyYMax) joyYMax = jy;
  if (jx < joyXMin) joyXMin = jx;
  if (jx > joyXMax) joyXMax = jx;

  // ---- CSV output ----
  Serial.print(pw1); Serial.print(",");
  Serial.print(pw2); Serial.print(",");
  Serial.print(pw4); Serial.print(",");
  Serial.print(pw5); Serial.print(",");
  Serial.print(jy);  Serial.print(",");
  Serial.print(jx);  Serial.print(",");
  Serial.print(1500); Serial.print(",");
  Serial.print(1500); Serial.print(",");
  Serial.println(0);

  // ---- Summary every 10s ----
  uint32_t now = millis();
  if (now - lastSummary >= SUMMARY_INTERVAL) {
    lastSummary = now;
    float elapsed = (now - startTime) / 1000.0;

    Serial.print("# --- SUMMARY at ");
    Serial.print(elapsed, 0);
    Serial.println("s ---");

    printRcSummary("RC CH1 [D2] left ", pw1);
    printRcSummary("RC CH2 [D4] right", pw2);
    printRcSummary("RC CH4 [D3] mode ", pw4);
    printRcSummary("RC CH5 [D7] ovrd ", pw5);

    float minVY = (joyYMin / 16383.0) * 5.0;
    float maxVY = (joyYMax / 16383.0) * 5.0;
    float minVX = (joyXMin / 16383.0) * 5.0;
    float maxVX = (joyXMax / 16383.0) * 5.0;

    Serial.print("#   Joy Y [A0] range: ");
    Serial.print(minVY, 3); Serial.print("V - ");
    Serial.print(maxVY, 3); Serial.println("V");

    Serial.print("#   Joy X [A1] range: ");
    Serial.print(minVX, 3); Serial.print("V - ");
    Serial.print(maxVX, 3); Serial.println("V");

    Serial.println("# ---");
  }
}

void printRcSummary(const char* label, uint32_t pw) {
  Serial.print("#   ");
  Serial.print(label);
  Serial.print(": ");
  if (pw == 0) {
    Serial.println("NO SIGNAL");
  } else if (pw < 900 || pw > 2200) {
    Serial.print(pw); Serial.println("us — OUT OF RANGE");
  } else {
    Serial.print(pw); Serial.print("us — OK");
    if (pw > 1450 && pw < 1550) Serial.println(" (centered)");
    else if (pw < 1100) Serial.println(" (LOW)");
    else if (pw > 1900) Serial.println(" (HIGH)");
    else Serial.println();
  }
}

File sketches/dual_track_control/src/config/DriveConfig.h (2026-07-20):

// config — drive/output tunables: servo authority, per-gear caps, pivot
// blend (#185).
#pragma once

// Servo PWM range (matches GL10's standard 50 Hz, 1-2 ms input spec)
const int SVC   = 1500;  // Center (neutral)
const int SVMIN = 1000;  // Full reverse
const int SVMAX = 2000;  // Full forward

// ── Throttle output caps ──────────────────────────────────────────────────
// All caps below are MAX TRACK-OUTPUT fractions (0..1). A straight-line track
// output = xSpeed * gearScale, so each cap is converted to the xSpeed domain
// via outCapToX() at point of use — one helper, no scattered conversions.

// Per-gear joystick FORWARD cap (#90) — the joystick rider's max forward track
// output per gear (RC keeps the gear's full authority). Throttle axis only;
// steering / pivot unaffected.
const float JOY_CAP_ECO    = 0.65f;  // Eco
const float JOY_CAP_NORMAL = 0.75f;  // Normal
const float JOY_CAP_BOOST  = 0.90f;  // Boost

// REVERSE caps (#87/#113) — per gear, flat across BOTH inputs (RC + joystick).
// Reverse is held below forward authority; Boost is allowed a little more reverse
// than Eco/Normal. Applied through reverseCap() (defined with the other gear-cap
// helpers in the sketch) so there is ONE source of truth, not a scattered
// conditional. These are TRUE percentages only because the GL10s were
// recalibrated to the full 1000/1500/2000 us range on 2026-07-03. Previously
// they were calibrated while the firmware capped reverse at 65%, so they
// mislearned 65% as 100% reverse — which made a 65%-commanded reverse drive
// ~100%. Do NOT lower the firmware reverse cap and recalibrate at the same
// time, or that mislearning returns.
const float REVERSE_CAP_STD   = 0.55f;  // Eco + Normal
const float REVERSE_CAP_BOOST = 0.65f;  // Boost

// Power range — full PWM authority (1000-2000 us = ±500 us from SVC)
const float SOFT_RANGE = 500.0f;  // Max servo offset from center (us)

// Gear scaling — RC CH4 selects the AVERAGE-speed cap. 3-position switch:
//   LOW  → 65% average-speed cap  (training / tight spaces)
//   MID  → 80% average-speed cap  (normal driving — the everyday gear)
//   HIGH → 100% (the rail)        (full throttle authority)
// The cap limits the AVERAGE track speed, not each wheel: in a turn the outer
// track may use the headroom up to the ESC limit so the turn holds its speed
// (see curvatureDrive). Boost has no headroom (already at the rail).
// Failsafe: when S.BUS is invalid, gearScale stays at LOW for safety.
const float GEAR_LOW_SCALE  = 0.65f;  // Eco   (+10pp 2026-06-21 for usefulness; keeps ~35% turn headroom)
const float GEAR_MID_SCALE  = 0.80f;  // Normal (+10pp 2026-06-21 — the everyday gear; keeps ~20% turn headroom)
const float GEAR_HIGH_SCALE = 1.00f;  // Boost  (no turn headroom — at the rail)

// Eco gets extra PIVOT authority so the operator can still maneuver in tight
// spaces (pivot input cap; forward stays at GEAR_LOW_SCALE 65%). Effective pivot
// wheel speed = pivot cap × gear scale: 0.725 × 0.65 = 0.47 (vs 0.60 × 0.65).
// (Reverse is capped per gear via reverseCap(): 55% Eco/Normal, 65% Boost.)
const float PIVOT_SPEED_CAP_LOW = 0.725f;

// Curvature drive — pivot/curvature blend band.
// |xSpeed| <= START: pure pivot (counter-rotate at PIVOT_SPEED_CAP)
// |xSpeed| >= END:   pure curvature (outer holds the average, inner slows)
// Between: smoothstep blend so the operator doesn't feel a mode jump. The band
// is WIDE (0.05–0.55) so the pivot↔forward/reverse hand-off is gradual — a
// narrow band made the transition snap near 15–20% throttle (#72).
const float PIVOT_BLEND_START = 0.05f;
const float PIVOT_BLEND_END   = 0.55f;
const float PIVOT_SPEED_CAP   = 0.60f;  // pivot rotation cap (~60% wheel power)
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

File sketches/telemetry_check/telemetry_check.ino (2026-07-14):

// ═══════════════════════════════════════════════════════════════
// X.BUS Telemetry Check — READ-ONLY bench tool (issue #36)
// ═══════════════════════════════════════════════════════════════
//
// PURPOSE: Confirm X.BUS telemetry comes through from BOTH GL10 ESCs on
// the post-migration circuit. Proven 0x50 framing (confirmed on GL10
// 2026-05-23), but throttle is HARD-WIRED to 0 — this sketch NEVER drives
// the motors. No joystick, no RPM loop, no step test. Telemetry only.
//
// Board: Arduino UNO R4 WiFi   FQBN: arduino:renesas_uno:unor4wifi   Port: COM7
// X.BUS on Serial1 (D0 RX / D1 TX), 115200 8N1, non-inverted, bus pull-up.
//   D1 (TX) --[1K]--+-- both ESC X.BUS yellow wires
//   D0 (RX) --------+
//   ESC brown -> GND (common),  ESC red (BEC) -> NOT CONNECTED
//
// NOTE: 0x50 puts the ESC in BUS_MODE. Safe here because we only ever send
// throttle = 0. The real telemetry feature in dual_track_control will use Read Register
// (0x10) so it can coexist with PWM driving — see issue #36.

const uint8_t  NUM_ESCS        = 2;
const uint8_t  HEADER_MASTER   = 0x0F;
const uint8_t  HEADER_SLAVE    = 0xF0;
const uint8_t  ADDR_BROADCAST  = 0xFF;
const uint8_t  FUNC_THROTTLE   = 0x50;
const uint8_t  FUNC_RESTART    = 0xA0;
const uint8_t  TELEM_DATA_LEN  = 17;   // Length field reported by ESC
const uint8_t  TELEM_FRAME_LEN = 22;   // total on-wire bytes
const uint32_t TELEM_TIMEOUT_US = 5000;
const uint32_t POLL_PERIOD_MS   = 50;  // 20 Hz poll, alternating ESCs
const uint32_t PRINT_PERIOD_MS  = 500;  // 2 Hz print

struct ESCTelemetry {
  int16_t  rpmHz, busCurrent, phaseCurrent;
  uint16_t status;
  int16_t  receivedThrottle, outputThrottle, busVoltage, escTempRaw;
  bool     valid;
  uint32_t timestamp;
};
ESCTelemetry telem[NUM_ESCS];

uint8_t  txBuf[40], rxBuf[40];
int      rxLen = 0;
uint8_t  telemTarget = 0;
uint32_t lastPollMs = 0, lastPrintMs = 0;
uint32_t totalPolls = 0, goodFrames = 0, badFrames = 0;
uint32_t lastBusModeMs = 0, lastRestartMs = 0;
bool     firstGood = true;

uint8_t checksumFull(const uint8_t *f, int len) {
  uint8_t s = 0; for (int i = 1; i < len - 1; i++) s += f[i]; return s;
}
uint8_t checksumNarrow(uint8_t sadr, uint8_t extra) { return (sadr + extra) & 0xFF; }

// Send broadcast throttle (ZERO for both ESCs) + request telemetry from target
void sendZeroThrottle(uint8_t target) {
  int dataLen = NUM_ESCS * 2;
  int frameLen = 6 + dataLen;
  txBuf[0] = HEADER_MASTER;
  txBuf[1] = ADDR_BROADCAST;
  txBuf[2] = target;            // telemetry responder
  txBuf[3] = FUNC_THROTTLE;
  txBuf[4] = dataLen;
  for (uint8_t i = 0; i < NUM_ESCS; i++) {   // throttle 0 for every ESC
    txBuf[5 + i * 2] = 0x00;
    txBuf[6 + i * 2] = 0x00;
  }
  txBuf[frameLen - 1] = checksumFull(txBuf, frameLen);
  while (Serial1.available()) Serial1.read();
  Serial1.write(txBuf, frameLen);
  Serial1.flush();
}

void sendRestart(uint8_t target) {
  txBuf[0] = HEADER_MASTER; txBuf[1] = ADDR_BROADCAST; txBuf[2] = target;
  txBuf[3] = FUNC_RESTART;   txBuf[4] = 0; txBuf[5] = checksumFull(txBuf, 6);
  Serial1.write(txBuf, 6); Serial1.flush();
}

bool receiveTelemetry(uint8_t esc) {
  uint32_t start = micros(); rxLen = 0;
  while ((micros() - start) < TELEM_TIMEOUT_US) {
    while (Serial1.available() && rxLen < (int)sizeof(rxBuf)) rxBuf[rxLen++] = Serial1.read();
    for (int i = 0; i + TELEM_FRAME_LEN <= rxLen; i++)
      if (rxBuf[i] == HEADER_SLAVE && rxBuf[i + 1] == ADDR_BROADCAST &&
          rxBuf[i + 3] == FUNC_THROTTLE) {
        start = 0;
        break;
      }
    if (start == 0) break;
  }
  int fs = -1;
  for (int i = 0; i + TELEM_FRAME_LEN <= rxLen; i++)
    if (rxBuf[i] == HEADER_SLAVE && rxBuf[i + 1] == ADDR_BROADCAST &&
        rxBuf[i + 3] == FUNC_THROTTLE) {
      fs = i;
      break;
    }
  if (fs < 0 || (rxLen - fs) < TELEM_FRAME_LEN) return false;
  uint8_t *f = &rxBuf[fs];
  if (f[4] != TELEM_DATA_LEN) return false;
  uint8_t sum = checksumFull(f, TELEM_FRAME_LEN);
  if (f[TELEM_FRAME_LEN-1] != sum && f[TELEM_FRAME_LEN-1] != checksumNarrow(f[1], f[2])) return false;
  const uint8_t *d = &f[5];
  ESCTelemetry *t = &telem[esc];
  t->rpmHz            = (int16_t)(d[0]  | (d[1]  << 8));
  t->busCurrent       = (int16_t)(d[2]  | (d[3]  << 8));
  t->phaseCurrent     = (int16_t)(d[4]  | (d[5]  << 8));
  t->status           = (uint16_t)(d[6] | (d[7]  << 8));
  t->receivedThrottle = (int16_t)(d[8]  | (d[9]  << 8));
  t->outputThrottle   = (int16_t)(d[10] | (d[11] << 8));
  t->busVoltage       = (int16_t)(d[12] | (d[13] << 8));
  t->escTempRaw       = d[14];   // ESC temp is one byte (printed as raw − 40); d[15] is a separate field
  t->valid = true; t->timestamp = micros();
  return true;
}

void printRawRX() {
  if (rxLen == 0) {
    Serial.println("# RAW RX: (nothing)");
    return;
  }
  Serial.print("# RAW RX ("); Serial.print(rxLen); Serial.print("B): ");
  for (int i = 0; i < min(rxLen, 32); i++) {
    char h[4];
    snprintf(h, sizeof(h), "%02X ", rxBuf[i]);
    Serial.print(h);
  }
  Serial.println();
}

void setup() {
  Serial.begin(115200);
  Serial1.begin(115200);
  uint32_t w = millis(); while (!Serial && (millis() - w) < 2000) {}
  Serial.println();
  Serial.println("# X.BUS Telemetry Check (READ-ONLY, throttle hard-wired 0) — issue #36");
  Serial.println("# UNO R4 WiFi, Serial1 D0/D1 @115200. Reading BOTH ESCs (0 and 1).");
  for (uint8_t i = 0; i < NUM_ESCS; i++) telem[i].valid = false;
  delay(500);
  Serial.println("# Restart broadcast (0xA0) to activate BUS_MODE...");
  while (Serial1.available()) Serial1.read();
  sendRestart(0xFF);
  delay(200);
  lastPollMs = millis();
}
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

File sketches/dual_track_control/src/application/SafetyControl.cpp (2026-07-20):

// application — battery/thermal shim implementations (#189), verbatim
// from the .ino.
#include "SafetyControl.h"

#include "AlertControl.h"
#include "FirmwareState.h"
#include "../config/AlertConfig.h"
#include "../config/BatteryConfig.h"
#include "../config/ThermalConfig.h"
#include "../domain/battery/VoltagePlausibility.h"
#include "../domain/battery/BatteryLadder.h"
#include "../domain/thermal/ThermalHysteresis.h"
#include "../domain/thermal/ThermalDerating.h"
#include "../ports/ClockPort.h"

// ═══════════════════════════════════════════════════════════════
// [SAFETY] — staged low-battery protection (#65)
// ═══════════════════════════════════════════════════════════════
// MOTOR-AFFECTING (unlike [ALERT], which is audio-only). Two latched stages off
// the worst-of-two pack EMA, validity-gated + debounced, NO startup grace (the
// validity gate is the only warm-up guard). Both latch until power-cycle:
//   Stage 1 — Eco lock   (≤ ECO_LOCK_THRESH_V ~10.8 V): updateGear() forces Eco
//             regardless of the RC gear switch, to ease load on a draining pack.
//   Stage 2 — Hard cutoff (≤ CUTOFF_THRESH_V 10.0 V): the output gate stops the
//             motors, and alertNotifyBatteryCutoff() starts the D8 alarm WITH
//             the cut — never a silent cutoff (#119: [ALERT] owns its latch;
//             this module signals through that narrow interface).

uint32_t cutoffStartMs  = 0;
uint32_t ecoLockStartMs = 0;

// Worst-of-two pack voltage if BOTH packs read a plausible value; else false
// (a not-yet-powered pack reads ~0 V and must not trip anything).
// Logic extracted to src/domain/battery/VoltagePlausibility.* (#117 step 1);
// this delegate keeps both ladder call sites and the test surface unchanged.
bool worstPackVoltage(float* worst) {
  return worstPlausiblePackVoltage(
      BatteryReading{telem[0].voltage, telem[0].valid},
      BatteryReading{telem[1].voltage, telem[1].valid},
      LOWV_PLAUS_MIN_V, LOWV_PLAUS_MAX_V, worst);
}

// Both stages extracted to src/domain/battery/BatteryLadder.* (#117 step 2,
// #154); these delegate shims keep every call site and test reference
// unchanged. The shims own the boundary work the domain must not do: read
// the clock (time is a parameter), mirror the ladder globals in/out, and —
// on the cutoff's just-latched signal — start [ALERT]'s alarm WITH the cut
// (domain code never writes another module's state). The early returns
// preserve the original property that a latched stage reads no telemetry.

void batteryEcoLockUpdate() {        // Stage 1 — force Eco
  if (ecoLockLatched) return;
  float worst = 0.0f;  // stays unwritten when implausible; the step ignores it then
  bool plausible = worstPackVoltage(&worst);
  BatteryLadderState ladder{ecoLockLatched, batteryCutoffLatched,
                            batteryOkConfirmed, ecoLockStartMs, cutoffStartMs};
  batteryEcoLockStep(ladder, plausible, worst, clockNowMs(),
                     ECO_LOCK_THRESH_V, ECO_LOCK_DEBOUNCE_MS);
  ecoLockLatched = ladder.ecoLockLatched;
  ecoLockStartMs = ladder.ecoLockStartMs;
}

void batteryCutoffUpdate() {         // Stage 2 — hard cutoff
  if (batteryCutoffLatched) return;
  float worst = 0.0f;  // stays unwritten when implausible; the step ignores it then
  bool plausible = worstPackVoltage(&worst);
  BatteryLadderState ladder{ecoLockLatched, batteryCutoffLatched,
                            batteryOkConfirmed, ecoLockStartMs, cutoffStartMs};
  bool cutoffJustLatched = batteryCutoffStep(ladder, plausible, worst, clockNowMs(),
                                             CUTOFF_THRESH_V, CUTOFF_DEBOUNCE_MS);
  batteryCutoffLatched = ladder.cutoffLatched;
  batteryOkConfirmed   = ladder.okConfirmed;
  cutoffStartMs        = ladder.cutoffStartMs;
  if (cutoffJustLatched) {
    alertNotifyBatteryCutoff();      // start the D8 alarm WITH the cut (no silent cutoff)
  }
}

// ── [SAFETY] motor / ESC over-temperature protection (#111) ──────────────────
// NON-LATCHING with hysteresis (heat ≠ a drained LiPo: once cool, drive resumes).
// Source = hottest of all 4 sensors among FRESH valid reads only; a telemetry
// dropout holds the last state and never cuts.

uint32_t tempWarnSinceMs = 0;   // trip-debounce timers (0 = not currently above ON)
uint32_t tempEcoSinceMs  = 0;
uint32_t tempCutSinceMs  = 0;

// The thermal ladder is extracted to src/domain/thermal/ (#117 step 3, #158);
// these delegate shims keep every call site and test reference unchanged.
// The shims own the boundary work the domain must not do: read the clock
// (time is a parameter), flatten telem[] into ThermalReadings, mirror the
// stage globals in/out, and — on the domain's cut-released signal — queue
// [BEEPER]'s one-shot "restored" flourish (4 quick beeps; the repeating cut
// alarm has already stopped because tempCutActive just went false). Domain
// code never calls another module.

// Hottest plausible temp across both ESCs (ESC + motor sensor each). Returns
// false if neither ESC has a fresh valid plausible reading → caller HOLDS state.
bool hottestMotorTemp(float* hot) {
  ThermalReading readings[NUM_ESCS * 2];
  for (uint8_t i = 0; i < NUM_ESCS; i++) {
    readings[i * 2]     = ThermalReading{telem[i].escTempC, telem[i].valid};
    readings[i * 2 + 1] = ThermalReading{telem[i].motorTempC, telem[i].valid};
  }
  return hottestPlausibleTemperature(readings, NUM_ESCS * 2,
                                     TEMP_PLAUS_MIN_C, TEMP_PLAUS_MAX_C, hot);
}

void tempStageUpdate(bool* state, uint32_t* since, float temp,
                     float onC, float offC, uint32_t nowMs) {
  ThermalStageState stage{*state, *since};
  thermalStageStep(stage, temp, nowMs, onC, offC, TEMP_DEBOUNCE_MS);
  *state = stage.active;
  *since = stage.sinceMs;
}

void thermalUpdate() {
  float hot = 0.0f;  // defensive init: the out-param is left unchanged on reject
  bool haveReading = hottestMotorTemp(&hot);
  ThermalDeratingState derating{{tempWarnActive, tempWarnSinceMs},
                                {tempEcoActive,  tempEcoSinceMs},
                                {tempCutActive,  tempCutSinceMs}};
  bool cutReleased = thermalDeratingStep(
      derating, haveReading, hot, clockNowMs(),
      ThermalDeratingThresholds{TEMP_WARN_ON_C, TEMP_WARN_OFF_C,
                                TEMP_ECO_ON_C,  TEMP_ECO_OFF_C,
                                TEMP_CUT_ON_C,  TEMP_CUT_OFF_C,
                                TEMP_DEBOUNCE_MS});
  tempWarnActive = derating.warn.active;
  tempWarnSinceMs = derating.warn.sinceMs;
  tempEcoActive = derating.eco.active;
  tempEcoSinceMs = derating.eco.sinceMs;
  tempCutActive = derating.cut.active;
  tempCutSinceMs = derating.cut.sinceMs;
  if (cutReleased) beepStart(BEEP_THERM_RESTORED, BEEP_THERM_RESTORED_LEN);
}

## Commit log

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2026-03-15 Update plan: CH5 3-mode override, verified signals, bootloader fix
    - Override switch is receiver CH5 (not CH3), wired to D7
    - 3-position switch: remote-only / full override / 50% blended
    - All 3 RC channels verified (CH1 ~1500μs, CH2 ~1497μs, CH5 ~972-2060μs)
    - Corrected bootloader setting: NEW bootloader at 115200, not old
    - Added arduino-cli upload command for direct uploads
    - Documented pulseIn() blocking issue (confirmed by testing)
    - Added Nano R4 hardware section and migration plan
2026-03-15 Add RC channel test sketch for D2, D4, D7
    Reads servo PWM signals from 3 RC receiver channels using pulseIn().
    D4 is read first to work around pulseIn() blocking issue where
    sequential reads cause later channels to miss their pulse window.
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2026-03-15 Implement tank mixer V1 with override modes and EMA smoothing
    Replace the RC channel test sketch with the full tank mixer:
    - Read 3 RC channels (throttle, steering, 3-pos override) + 2 joystick axes
    - 3 override modes: RC-only, joystick with RC priority, 50/50 blend
    - Tank mix (left = throttle + steering, right = throttle - steering)
    - 800ms EMA smoothing on ESC outputs for gradual ramp
    - Failsafe: hold last RC values on dropout, neutral after 500ms
    - Deadbands: ±50μs RC, ±30 ADC joystick
    - Servo output on D9 (left ESC) and D10 (right ESC)
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2026-03-15 Replace blocking pulseIn with pin change interrupts for lag-free RC reads
    Major performance rewrite of the tank mixer:
    - Use PCINT2 ISR to decode all 3 RC channels simultaneously in hardware
    - Eliminates ~75ms/loop blocking from pulseIn — loop now runs at 1000+ Hz
    - Increase serial to 115200 baud to prevent TX buffer blocking (was 9600)
    - Rate-limit serial output to 20 Hz to keep protocol clean
    - Atomic reads of ISR values with interrupt guard
    - Validate pulse widths (800-2200us) in ISR to reject noise
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2026-03-15 Fix double-mixing: pass RC signals through, tank-mix only joystick
    The RC transmitter already outputs left/right motor signals (built-in
    tank mixing). Applying our tank mix formula on top caused only one ESC
    to respond when throttling — the second mix converted the already-mixed
    values into asymmetric output.
    Now RC CH1/CH2 are treated as direct left/right motor signals and passed
    through to the ESCs. Tank mixing is only applied to the joystick inputs
    (which output raw throttle/steering).
2026-03-15 Add 40% power cap and asymmetric EMA smoothing
    Safety and feel improvements:
    - Cap ESC output to 40% of full range (1300-1700us) to limit motor power
    - Asymmetric EMA: 800ms ramp-up (gentle acceleration), 400ms ramp-down
    (quick deceleration to avoid collisions)
    - Update live plot: zoom ESC panels to 1200-1800us, add red limit lines
2026-03-15 Use proportional power scaling instead of hard clamp
    Replace hard clamp at 40% with proportional scaling so the full stick
    travel maps to the 40% output range. Previously, any input past 40%
    was wasted (output stayed at 1300/1700). Now 50% stick = 20% output,
    100% stick = 40% output — smooth, proportional control with no dead zone.
2026-03-15 Update project plan to reflect actual V1.2 implementation
    Rewrite to match what was built:
    - RC signals are pre-mixed (left/right pass-through, not throttle/steering)
    - PCINT interrupt-based RC reading (replaces pulseIn)
    - Proportional 40% power scaling with full stick travel
    - Asymmetric EMA smoothing (800ms up, 400ms down)
    - Add signal processing pipeline diagram
    - Add tuning constants reference table
    - Update status checklist with completed milestones
2026-03-15 Add operator guide for Jason (RC) and Malaki (joystick)
    Plain-language guide explaining the dual-operator control system:
    - 3 override modes and when to use each
    - Joystick and RC control mapping
    - Safety features (40% power cap, asymmetric smoothing, failsafe)
    - Quick reference table for common operations
    - Tuning instructions for adjusting power limit and smoothing
2026-03-20 WIP: Migrate sketch to Arduino UNO Q V2.0 with PID current limiting and inertia sim
    Initial migration from Nano V3 (ATmega328P) to UNO Q (STM32U585):
    - attachInterrupt() replaces AVR PCINT registers
    - 14-bit ADC (16384 steps) with 3.3V reference
    - Exponential response curve (2.5 exponent) for excavator feel
    - Physics-based inertia simulation replacing EMA smoothing
    - PID current limiter with soft/hard thresholds per motor
    - Current sensor inputs on A2/A3 with moving average
    - Power limit raised to 50%
    NOTE: This is WIP — needs revision for CS7581 sensor specs, adaptive
    PID gains, 8-ton inertia dynamics, and exponential soft saturation.
    https://claude.ai/code/session_019Tmgsnm53pAmPKjnAML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
2026-03-20 Migrate sketch to Arduino UNO Q V2.0 with full control pipeline
    Major rewrite from V1.2 (Nano V3) to V2.0 (UNO Q / STM32U585):
    - 20,000+ Hz loop rate via micros() timing, zero blocking
    - Spring-damper inertia simulation replacing EMA smoothing
    - CS7581 hall-effect current sensors on A2/A3 (per motor)
    - PID current limiter with adaptive gain scaling (lower gains
    under heavy load for stability)
    - Exponential soft saturation via tanh() — no hard clamps
    - Anti-runaway failsafe: if PID correction stuck at max for 2s,
    go neutral and la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
2026-03-20 Fix PID: boost power to overcome resistance, not reduce it
    The PID was backwards — it was reducing power under load (overcurrent
    protection). The correct behavior for an excavator is to BOOST power
    when a track encounters resistance (mud, cold rubber, obstacles) to
    maintain consistent speed. This is "cruise control for tracks."
    PID now:
    - Estimates expected current from commanded output level
    - Detects resistance when measured current > expected
    - Adds boost (extra us) in the direction of travel
    - Soft ceiling via tanh() prevents abrupt compensation jumps
    - Adaptive gains: lower at high speed (stability), higher at
    low speed (responsive maneuvering)
    Safety layers:
    - COMP_MAX_BOOST (50u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
2026-03-21 Update project plan: dual-loop PID architecture and X.BUS-first strategy
    Major architecture change from single-loop to dual-loop control:
    - Inner loop (feedforward): CS7581 current sensors detect load spikes
    instantly, pre-compensate before RPM drops
    - Outer loop (feedback): RPM measurement confirms actual motor speed,
    fine-tunes to hold target — disturbances absorbed before operator feels them
    RPM source strategy: X.BUS telemetry first (ESC's dedicated serial wire),
    fall back to direct motor hall sensor tap if X.BUS update rate is too slow.
    Updated: inventory, inputs table, wiring diagram, pin summary, signal
    processing pipeline, software section, and status checklist with clear
    dec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
2026-03-21 Upgrade sketch to V2.1: dual-loop PID with X.BUS and hall sensor support
    Full rewrite of the control pipeline from single-loop current-only PID to
    dual-loop feedforward + feedback architecture:
    Inner loop (current feedforward, 20kHz):
    CS7581 current sensors detect load spikes instantly. When a track hits
    resistance, current spikes BEFORE RPM drops. Pre-boosts power to
    compensate before the operator feels anything.
    Outer loop (RPM feedback, X.BUS rate or hall rate):
    Measures actual motor speed via X.BUS telemetry or hall sensor tap.
    Applies trim correction on top of the feedforward — confirms whether
    compensation actually maintained speed, fine-tunes if not.
    RPM source switch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
2026-03-21 Add CH4 control mode selector: RAW / RPM_ONLY / FULL_STACK (V2.2)
    RC CH4 on D3 (3-position switch) selects the control pipeline at runtime:
    LOW = RAW: Direct stick-to-ESC, no processing layers.
    Linear joystick map, hard power clamp. Baseline.
    MID = RPM_ONLY: Outer RPM PID loop only. Speed regulation without
    expo curve, inertia, or current feedforward.
    HIGH = FULL_STACK: All layers active — inner current feedforward +
    outer RPM feedback + expo curve + inertia sim +
    soft power limits + anti-runaway.
    This enables A/B/C field testing by flipping one switch:
    - RAW: feel the unprocessed respo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
2026-03-22 Finalize dual X.BUS UART architecture: D0 + PG8 (JMISC), debug on D8
    UART architecture decision (LLEXT firmware constraint):
    - Serial (USART1/D0): Left ESC X.BUS telemetry (hardware UART)
    - Serial1 (LPUART1/PG8): Right ESC X.BUS telemetry (hardware UART, JMISC solder)
    - Bit-bang TX on D8: Debug output to USB-to-serial adapter
    Changes:
    - CLAUDE.md: Updated pin assignments, added UART architecture section
    - PROJECT-PLAN.md: Updated wiring diagram to V2.2, pin summary, status checklist
    - xbus_probe.ino: Replaced Serial/Serial1 with DBG/XBUS_SERIAL macros,
    added SoftTX bit-bang class for debug output, configurable bench/field mode
    - live_plot.py: Updated docs for USB-to-serial adapter COM por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
2026-03-30 Correct X.BUS architecture: shared UART bus on D0, not I2C, PG8 reserved
    Major corrections based on research:
    - XC E10 "X.BUS" is NOT Spektrum X-Bus (I2C) — it has one data wire,
    which physically cannot be I2C (requires SDA + SCL)
    - Industry survey: 8-10 of 12 major ESC brands use UART serial for telemetry
    - Serial1/LPUART1 (PG8) is RESERVED by Arduino Router bridge — cannot use
    - Both ESCs share one bus on D0 (X.BUS supports 16 addressed ESCs)
    - Updated wiring diagram to V2.3 with shared bus topology
    - Freed D5/D6 (no longer needed for hall sensor fallback)
    - Updated next steps: probe protocol, then full X.BUS telemetry + throttle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
2026-03-30 V2.3: Lean sketch with expo + inertia, X.BUS raw capture, Monitor output
    - Active layers: exponential curve (2.5) + inertia simulation (spring-damper)
    - PID layers bypassed (current feedforward + RPM feedback disabled)
    - All inputs active: RC CH1/CH2/CH4/CH5, Joystick Y/X
    - ESC outputs active: D9/D10 driving motors
    - X.BUS on D0: passive baud-rate scanning + raw hex dump
    - Output via Monitor (Router Bridge -> USB) at 10 Hz
    - Joystick voltage displayed with warning if >3.2V
    - Replaced powf/tanhf with inline implementations (Zephyr linker fix)
    - Removed CS7581 current sensor and hall sensor code
2026-04-01 Diagnostic sketch v2.1: pulseIn for all RC, ADC crosstalk fix
    attachInterrupt() only works on D2/D3 on Nano R4 — switched all
    RC channels to pulseIn(). Added double-read with settling delay
    on joystick ADC to eliminate channel crosstalk (correlation dropped
    from 0.925 to 0.387). Added pin_test sketch for isolating interrupt
    vs wiring issues.
2026-04-01 Update live plot labels with pin annotations and comment filtering
    Each panel now shows both channel name and Arduino pin (e.g.
    "RC CH1 Left Motor [D2]"). Added filtering to skip comment lines
    (starting with #) from diagnostic sketch output.
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2026-04-01 V2.4: Fix pin assignments, pulseIn for CH2/CH5, ADC crosstalk fix
    - Correct pins: D2=CH1, D4=CH2, D3=CH4, D7=CH5 (was D8, D12)
    - CH2/CH5 use pulseIn instead of polling (fixes 83% value swapping)
    - Joystick ADC double-read with settling delay (crosstalk fix)
    - X.BUS passive capture with baud scan + D0 raw signal detection
    - Expo + inertia + soft limits + failsafe all active
    - Known issues: RC override logic needs rework, expo too aggressive,
    inertia jerky due to pulseIn blocking (~50ms/loop)
2026-04-01 V2.5: Fix override logic, loop speed, expo curve, inertia tuning
    1. Override (CH5): LOW=RC only, MID=RC priority, HIGH=Joystick only
    - Thresholds adjusted for actual switch range (1400/1600)
    2. Loop speed: alternating pulseIn (one channel per loop, ~40Hz)
    - Fixes CH2/CH5 swapping, doubles loop rate from 20Hz to 40Hz
    3. Expo: pow(1.8) blend instead of pow(2.5), SOFT_RANGE 400us (was 250)
    - 25% stick now gives 12% output (was 3% — felt dead)
    4. Inertia: mass=1.5 fric=5.0 resp=30.0 (tuned for 40Hz loop)
    - Lighter, smoother, faster tracking
    Known: expo/inertia may need further field tuning.
2026-04-02 V3.1: Fix stale timestamp bug, non-blocking RC, modular architecture
    Root cause: pulseIn() blocked 25ms, making micros() timestamps stale.
    ISR-updated timestamps appeared "in the future" vs the stale reference,
    causing unsigned wraparound in failsafe checks. Both channels showed
    valid=false even with strong RC signal. Left ESC partially responded
    (intermittent ISR timing), right ESC was completely dead.
    Fixes:
    - Replace pulseIn() with non-blocking PulseReader (edge detection via
    digitalRead polling — zero blocking, same accuracy at 48MHz)
    - Fresh micros() in rcSnapshot() — never reuse pre-blocking timestamps
    - Per-channel failsafe (each channel independently returns neutral)
    New feat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
2026-04-02 V3.2: Retune for 50lb machine — faster inertia, 35% reverse/spin limits
    Machine is ~50 lbs and 4-5 ft long, not 3 tons. Previous inertia
    (1.5s/3.0s) made it feel like driving through mud. Retuned for nimble
    but smooth response appropriate to actual size.
    - TAU_ACCEL: 1.5s → 0.3s (responsive acceleration)
    - TAU_DECEL: 3.0s → 0.5s (brief coast, predictable stop)
    - SPIN_LIMIT: 50% → 35% (safer pivot turns)
    - REVERSE_LIMIT: 50% → 35% (safer backward speed)
    - EXPO_LINEAR: 20% → 30% (more low-speed authority for tight spaces)
    - EXPO_SQUARE: 80% → 70% (still smooth at high stick)
    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
2026-04-02 V3.3: Rate-limit ADC to fix PulseReader edge detection jitter
    analogRead() blocked ~800us every loop iteration, starving the
    PulseReader of polling cycles. RC2/RC5 showed alternating values
    (missed edges during ADC window). Fixed by caching joystick ADC
    reads at 100Hz (every 10ms) instead of every iteration. Most loop
    iterations now run in ~50us (pure polling + math), giving ~20kHz
    edge detection rate.
2026-04-02 V3.4: Fix mixer Mode 3 to 50/50 blend, add coding rules
    Mode 3 (CH5 HIGH) was coded as "joystick only" — completely excluding
    RC input. The documented spec requires 50/50 blend (RC + joystick
    averaged). RC must ALWAYS have control in all three modes; the switch
    only controls joystick authority.
    Fix: Mode 3 now computes output = SVC + ((RC - SVC) + (Joy - SVC)) / 2
    Also:
    - CLAUDE.md: updated to V3.4, added Coding Rules section
    - PROJECT-PLAN.md: corrected override switch table
    - live_plot.py: updated CSV format for V3.x (CH1ok,CH2ok)
2026-04-02 V3.4: Reduce reverse and spin limits from 35% to 25%
    Per user request — 25% is safer for the 50lb machine.
    SPIN_LIMIT: 0.35 → 0.25
    REVERSE_LIMIT: 0.35 → 0.25
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2026-04-02 Fix version string mismatch: header comments now say V3.4
    rc_test.ino header and types.h both said V3.1 while the debug banner
    printed V3.4. Aligned all version references.
    Addresses PR #11 Copilot review comments 5 and 6.
2026-04-02 Fix deploy.py docstring: remove nonexistent board.cfg reference
    Addresses PR #11 Copilot review comment 9.
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2026-04-02 Update PROJECT-PLAN.md tuning constants to match V3.4 code
    Expo, inertia, spin, reverse values were stale from V3.1. Updated
    to match current deployed configuration. Version ref V3.1 → V3.4.
    Addresses PR #11 Copilot review comment 13.
2026-04-02 Update live_plot ESC reference lines to match SOFT_RANGE and reverse limit
    Old lines at 1250/1750 didn't match actual config (SOFT_RANGE=400,
    REVERSE_LIMIT=25%). Updated to 1100/1900 with reverse limit at 1400.
    Addresses PR #11 Copilot review comment 15.
2026-04-02 V4.0: Migrate RC input from 4x PWM to S.BUS single-wire protocol
    Replaced 4 separate PWM channels (2x ISR + 2x PulseReader on D2/D3/D4/D7)
    with S.BUS on D0 (Serial1 RX) via NPN inverter circuit. All RC channels
    now arrive on a single wire at 143Hz with receiver-reported failsafe.
    - [RC] module: ~80 lines of ISR/PulseReader → ~20 lines of S.BUS
    - types.h: removed RCChannel and PulseReader structs (no longer needed)
    - S.BUS values (172-1811) mapped to PWM-equivalent (1000-2000) so
    mixer/dynamics/output modules are unchanged
    - Failsafe uses receiver flag (14ms response) instead of 500ms timeout
    - Added sbus_test sketch for standalone signal verification
    - Freed pins: D2, D3 (inter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
2026-04-02 Add X.BUS inverted test sketch, clean V4.0 D2 probe residue
    xbus_inverted_test: standalone sketch that scans 7 baud rates on D2
    via NPN inverter. Used to confirm X.BUS is electrically dead (zero
    toggles even while motors running). Kept for future diagnostics.
2026-04-02 Safety: add S.BUS frame timeout to catch wire disconnect
    sbusValid could remain true indefinitely if frames stopped arriving
    (wire unplugged, Serial1 stalled) because it was only updated inside
    the Read() callback. Now tracks last frame timestamp and forces
    sbusValid=false after 100ms with no frames.
    Addresses PR #13 Copilot review comment 1.
2026-04-02 Fix debug telemetry rc5 default to match rcOverride() behavior
    Debug printed SVC (1500) when S.BUS invalid, but rcOverride() returns
    SVMIN (1000 = RC-only mode). CSV now reflects actual mixer behavior.
    Addresses PR #13 Copilot review comment 2.
2026-04-02 Fix xbus_inverted_test: reporting spam and unused variable
    Replace modulo-based report window with dedicated lastReport timestamp
    to print exactly once per 2s interval. Remove unused scanStart variable.
    Addresses PR #13 Copilot review comments 3 and 4.
2026-04-02 Safety: disable all output when RC transmitter is off
    Explicit sbusValid gate before the mixer. When RC is off (failsafe
    or no frames), both ESCs get neutral regardless of joystick position.
    No RC = no movement.
    Resolves #14.
2026-04-02 V4.1: Balance pivot turns — skip reverse limit during counter-rotation
    The reverse limiter was clipping the backward track after the spin
    limiter had already balanced both tracks proportionally. Example:
    spin limiter gives L=+250 R=-125, then reverse limit caps R to -100,
    breaking the balance. Now reverse limit only applies during straight-
    line backing (both tracks negative). During turns (counter-rotation),
    the spin limiter alone handles safety.
    Resolves #15.
2026-04-05 V4.2: Pivot balance for equal 360 turns + cubic expo curve
    Pivot balance: when tracks counter-rotate, force both to equal magnitude.
    The faster track sets the speed for both. Ensures clean 360 pivots with
    no drift or mid-turn correction needed.
    Cubic expo curve: replaces 30/70 linear/quadratic blend with pure cubic
    (power 3). At 50% stick = 12.5% output. Gentle creep in first half,
    fast ramp in second half. Instant response but slow buildup.
    Processing order: spin limiter → reverse limiter → pivot balance →
    soft limit → inertia.
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2026-04-05 ci: add permissions: contents: read to all workflows; fix Copilot instructions platform accuracy
    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
2026-04-05 fix: address Copilot review — use prune for docs/ exclusion, fix nested dir matching for .md and .github
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2026-05-11 docs: preserve plant characterization and project mission from V6/V7-FF era (#28)
    Bring forward the artifacts that retain value after the GL10 FOC swap
    made the V6/V7-FF closed-loop controller obsolete:
    - docs/MISSION.md — project constitution (smoothness-above-all rule).
    Still applies under FOC; the rule is hardware-agnostic.
    - docs/PLANT-CHARACTERIZATION.md — measured plant response of the
    E10/E3665 combo: 0–6% hard dead zone, 7–10% unreliable transition
    (41% variance), 15–60% reliable region. Useful as a baseline for
    any future hardware comparison.
    - docs/measurements/{deadzone,staircase_5runs,step_test}.csv — raw
    capture data from the V7-FF plant tests.
    The FF/tri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
    [deadzone.csv, staircase_5runs.csv, step_test.csv]
2026-05-23 V7: GL10 FOC migration + V7.1 tuning + V7.2 inertia removal (#38)
    * V7.0 (WIP): add Gear, BeepPattern, EscTelem, DriveCommand structs
    Checkpoint of types.h for the FOC migration (XC GL10 ESCs + GL540L motors).
    DriveCommand is the normalized (xSpeed, zRotation) pair that feeds the new
    60/60 cooperative blend at the command level (before curvatureDrive).
    WheelSpeeds is the post-gear, pre-PWM stage (CH4 selects 50/70/100%).
    EscTelem holds X.BUS Read-Register telemetry (battery V, motor/ESC temp).
    BeepPattern is a priority-ordered enum for the safety buzzer state machine.
    The full V7.0 sketch rewrite (rc_test.ino), docs updates, and PR are still
    pending — this commit just unblocks the stop h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
2026-05-25 V8: UNO R4 WiFi migration docs, GL10 reference, interface board schematic
    Cherry-picked from claude/design-daughter-board-2OsZS (commits made
    after PR #41 was merged). Contains:
    - WIRING-GUIDE-V8.md: complete UNO R4 WiFi pin map, UART architecture
    (SCI0 on D12 for S.BUS, SCI2 on D0/D1 for X.BUS), 9-pin modular
    cable spec with wire colors, power from BEC 7.4V→VIN, all 3-pin
    servo connectors
    - GL10-QUICK-REFERENCE.md: calibration (Reverse→Forward→Neutral),
    LED/beep codes, all 18 configurable parameters
    - GL10-Manual.pdf: official XC-ESC manual
    - INTERFACE-BOARD-NETLIST.md: BOM and 9-net wiring table for EasyEDA/KiCad
    - interface-board.kicad_sch + interface-board-easyeda.json: sc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
    [interface-board.kicad_sch]
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2026-05-26 review: fix markdownlint, F6 labeling, A4/A5 note, KiCad 3-pin, defaults clarity
    - Fix markdown table spacing and blank-line-before-list (markdownlint MD060/MD032)
    - Fix "timeout" → "time out" verb form
    - F6 power connector: label pin numbers explicitly to avoid confusion
    with standard Signal/VCC/GND column headers
    - A4/A5: relabel from "Free" to "I2C SDA/SCL" (they are dedicated I2C)
    - GL10 defaults: clarify table shows factory defaults, not our tuned values
    - KiCad schematic: J3/J4/J6 changed from Conn_01x02 to Conn_01x03
    to match the all-3-pin-servo standardization
    [interface-board.kicad_sch]
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2026-05-31 V8: confirm UNO R4 WiFi bring-up + S.BUS verified on hardware
    - Add docs/FIRMWARE-UPLOAD-LOG.md with first UNO R4 WiFi upload row
    - Log 2026-05-31 S.BUS hardware verification + inverter wiring fix
    - Fix .claude/settings.json hook event (PostToolCall -> PostToolUse)
    and matchers so the decision-log hooks actually fire
    - gitignore transient .claude/worktrees/
2026-06-01 ci: fix failing checks — disable MD060, drop obsolete serial2_test
    - markdownlint: disable MD060 (table-column-style), a newly-added rule in
    the unpinned markdownlint-cli that flagged pipe spacing across many
    pre-existing docs that render fine. Consistent with the other cosmetic
    rules already disabled (MD013/MD033/MD041).
    - arduino-ci: remove serial2_test from the compile matrix. It's a Nano R4
    A4/A5 sketch that can't build for the unor4wifi target (A4/A5 are
    I2C-only) and uses the forbidden `Serial2` instance name. Superseded by
    sbus_d12_test. Annotated the sketch + CLAUDE.md file map accordingly.
2026-06-01 review: address CodeRabbit threads on PR #46
    - rc_test: fix stale S.BUS wiring comment (A5 -> D12; base resistor 1K -> 10K
    to match INTERFACE-BOARD.md R3)
    - rc_test: extract sbusUart pins to named constants PIN_SBUS_TX/PIN_SBUS_RX
    (placed above the global UART so static-init sees them); binary unchanged
    - DECISION-LOG: show full 1375 us formula incl. 1500 neutral offset
    - settings.json: make PostToolUse hook prompts self-gating. Claude Code
    matchers match tool NAME only (not command/path), so narrowing to
    "git commit" isn't possible — instead the prompts now no-op unless the
    command was a commit / the target was the decision log.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
